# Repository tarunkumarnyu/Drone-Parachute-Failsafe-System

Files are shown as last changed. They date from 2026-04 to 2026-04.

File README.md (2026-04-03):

# Drone Failsafe Parachute System







An autonomous emergency recovery system for UAVs that detects in-flight failures and deploys a parachute with retractable landing gear for controlled descent — no pilot intervention required.

Built for the Mechatronics course (ROB-GY 5103) at NYU Tandon School of Engineering.

## Overview

Unmanned Aerial Vehicles are vulnerable to mid-flight failures — motor burnout, ESC faults, power loss — any of which can result in an uncontrolled crash. Conventional failsafes like return-to-home cannot recover from a dead motor or total power failure.

This system addresses that gap with a hardware-level emergency recovery pipeline built around the Parallax Propeller's multi-cog architecture. An MPU6050 IMU detects sudden acceleration anomalies (jerk-based freefall detection), triggering autonomous parachute deployment via servo-actuated topology-optimized release plates. Simultaneously, an HC-SR04 ultrasonic sensor monitors ground proximity and deploys spring-suspended retractable landing gear at a calibrated altitude threshold to absorb residual impact energy.

The entire pipeline — from failure detection to chute release to gear deployment — runs across dedicated parallel cogs with no shared blocking, achieving sub-100 ms end-to-end response latency.

<p align="center">
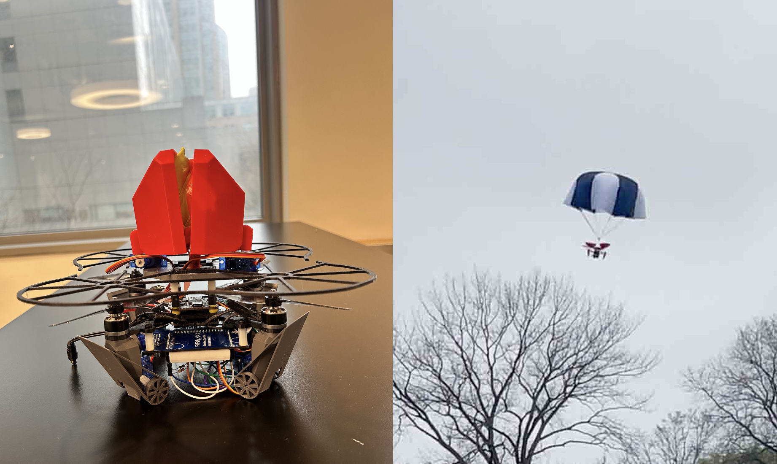
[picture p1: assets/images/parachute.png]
Drone Failsafe Parachute System
  
</p>

## Demo

https://github.com/user-attachments/assets/7736cbfe-6007-4965-8da9-a2f48488e733

https://github.com/user-attachments/assets/dcd64783-5e9d-4d79-8ad5-cde76a08081a
## How It Works

The firmware runs three concurrent processes on the Parallax Propeller's multi-core (cog) architecture, enabling true hardware-level parallelism with zero blocking between sensing and actuation:

**Stage 1 — Failure Detection (Cog 2: IMU Monitor)**

1. MPU6050 reads Z-axis acceleration at 20 Hz over I2C
2. Computes jerk (rate of change of acceleration) between consecutive readings
3. Sets an emergency flag when jerk exceeds the calibrated threshold — catches motor failure, ESC burnout, and freefall events

**Stage 2 — Parachute Deployment (Cog 0: Supervisor)**

1. Main supervisor loop detects jerk flag from IMU cog
2. Parachute servo rotates from armed (90°) to deployed (180°)
3. Topology-optimized plates open to allow clean chute separation from the airframe

**Stage 3 — Landing Gear Deployment (Cog 1: Ultrasonic Ranging)**

1. HC-SR04 continuously measures ground distance via pulse timing at ~10 Hz
2. When altitude drops below 35 cm, landing gear servo actuates
3. Spring-suspended 3D-printed gear absorbs remaining impact force

## System Architecture

<p align="center">
  Parallax Propeller Multi-Cog Architecture
</p>

## Components

| Component | Model | Qty | Purpose |
|---|---|-----|---|
| Microcontroller | Parallax Propeller P8X32A | 1 | Real-time multi-cog processing |
| IMU | MPU6050 | 1 | Z-axis jerk detection |
| Ultrasonic Sensor | HC-SR04 | 1 | Ground proximity ranging |
| Servo Motor | MG995 | 6 | Parachute release (2) + Landing gear (4) |
| Battery | 8.4V 2S LiPo | 1 | Main power supply |
| Buck Converter | — | 1 | 8.4V → 5V regulation |
| Drone Platform | Frame, FC, ESC, BLDC Motors | — | Flight platform |

## Pin Map

| Peripheral | Pin | Protocol |
|---|-----|---|
| MPU6050 SDA / SCL | P0, P1 | I2C |
| Parachute Servo | P2 | PWM |
| HC-SR04 Trig / Echo | P3 | GPIO |
| Landing Gear Servo | P4 | PWM |

## Design Decisions

- **Multi-cog concurrent sensing** — IMU and ultrasonic run on dedicated Propeller cogs for true parallel real-time processing with zero blocking
- **Jerk-based detection over tilt** — Computing the acceleration derivative catches sudden failures (motor loss, ESC burnout) faster than absolute tilt thresholds
- **Multi-stage descent sequencing** — Staged deployment (detect → chute → gear) inspired by proven planetary landing strategies
- **Topology-optimized release plates** — FEA-driven weight reduction while maintaining structural integrity and minimizing propeller wash drag
- **Spring-suspended landing gear** — Absorbs residual impact energy that the parachute alone cannot eliminate

## Results

- Autonomous parachute deployment on detected jerk events with <100 ms response latency
- Significant reduction in landing impact force across controlled test scenarios
- Reliable landing gear actuation at calibrated ground proximity threshold
- Validated against simulated motor failure, ESC burnout, and signal loss conditions

## Future Work

- Predictive stability control using onboard ML for preemptive deployment
- Adaptive deployment timing based on real-time environmental conditions (wind, altitude)
- Alternative energy absorption mechanisms (deployable air cushions, shock-absorbing retractable gear)
- Integration pathway for commercial drone platforms and regulatory compliance (FAA Part 107)

## Stack

`Parallax Propeller (C)` · `SimpleIDE` · `MPU6050` · `HC-SR04` · `MG995 Servos` · `SolidWorks` · `PLA-CF 3D Printing` · `LiPo Power System`

## Team

Tarunkumar Palanivelan · Sven Sunny · Abirami Palaniappan Sirsabesan

## License

This project is licensed under the [MIT License](LICENSE).

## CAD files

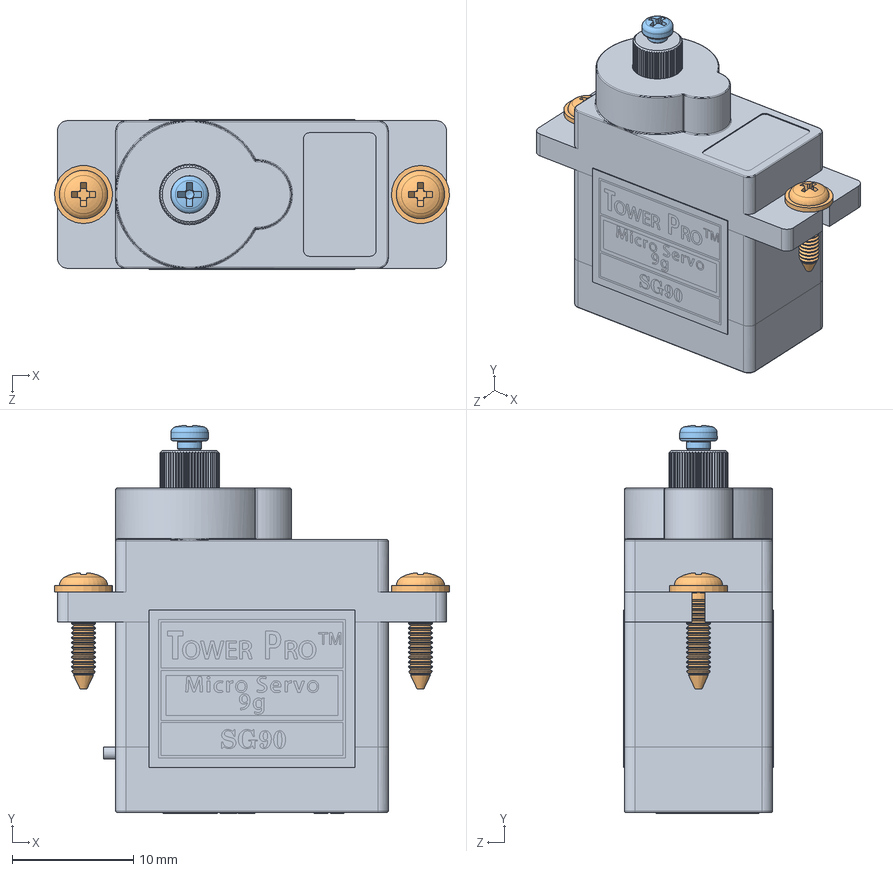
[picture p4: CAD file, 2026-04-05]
cadv2/SG90 - Micro Servo 9g - Tower Pro.SLDASM
32.6 x 32.0 x 12.4 mm
SG90 - Micro Servo 9g - Tower Pro.1
SG90 - Micro Servo 9g - Tower Pro.5 x 2
SG90 - Micro Servo 9g - Tower Pro.6

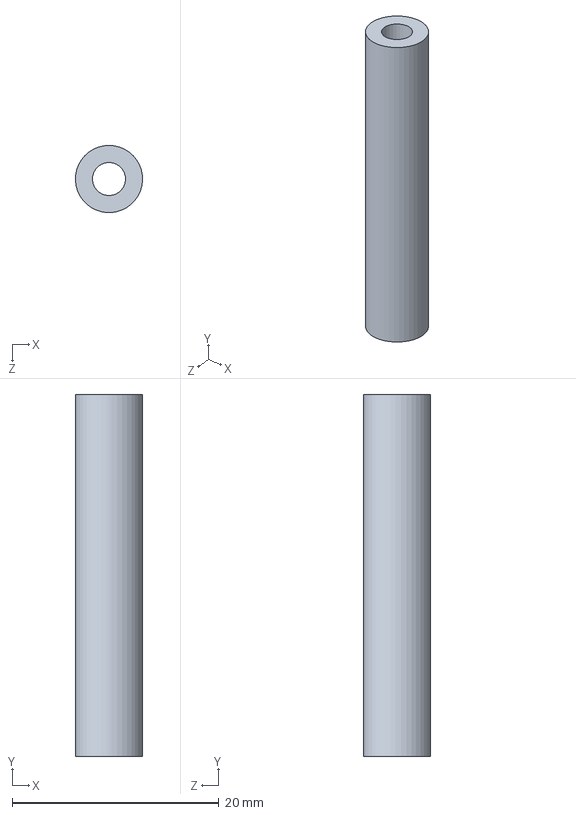
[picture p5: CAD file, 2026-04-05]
cadv1/spacers_35mm.SLDPRT
6.49 x 35.0 x 6.50 mm

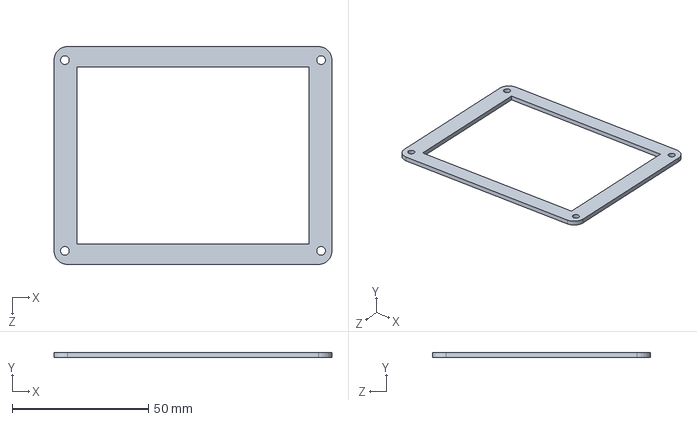
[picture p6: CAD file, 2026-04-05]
cadv2/servo holder.SLDPRT
102.0 x 2.00 x 80.0 mm

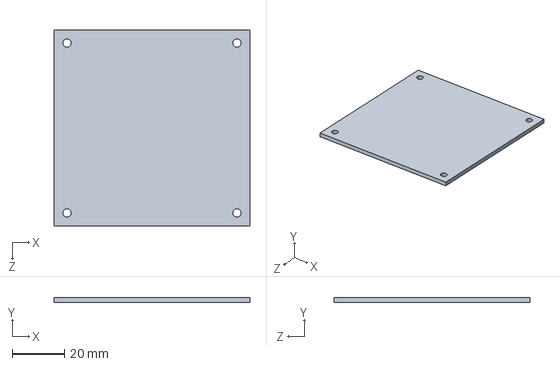
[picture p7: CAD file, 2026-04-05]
cadv1/arduino_attachment.SLDPRT
75.0 x 2.00 x 75.0 mm

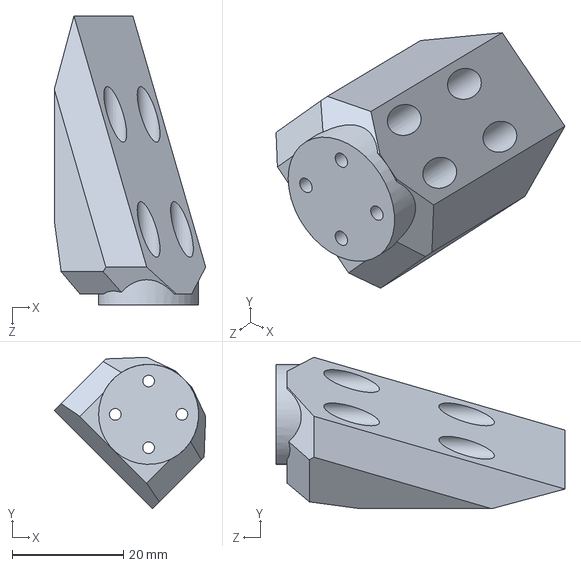
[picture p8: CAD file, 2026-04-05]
cadv2/lg.SLDPRT
27.2 x 27.2 x 52.0 mm

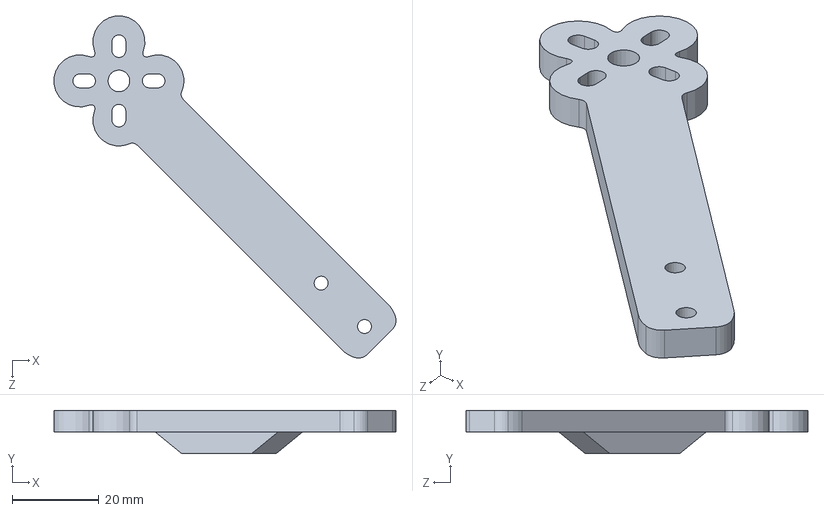
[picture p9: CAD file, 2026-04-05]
cadv1/frame_arms.SLDPRT
78.8 x 10.0 x 78.8 mm

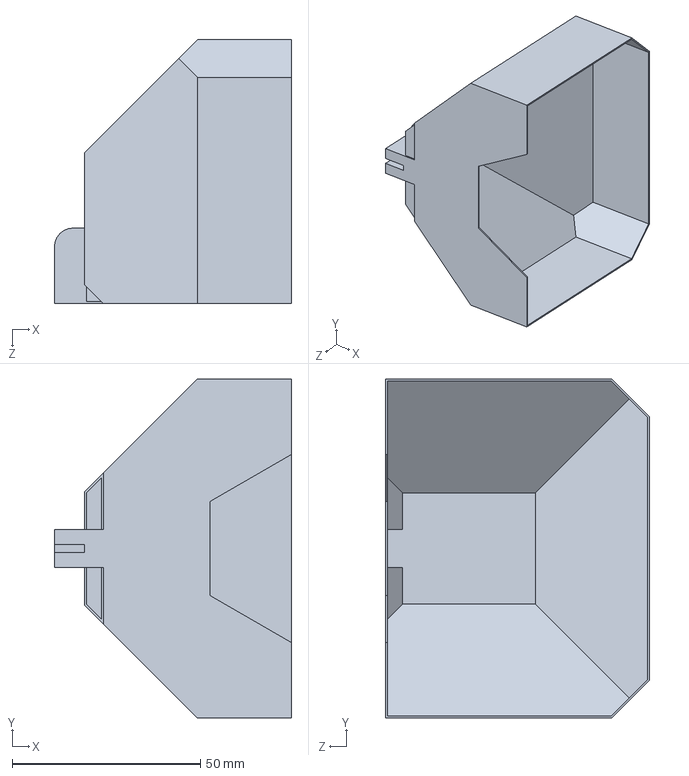
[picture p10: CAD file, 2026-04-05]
cadv2/parachute case.SLDPRT
63.0 x 90.0 x 70.0 mm

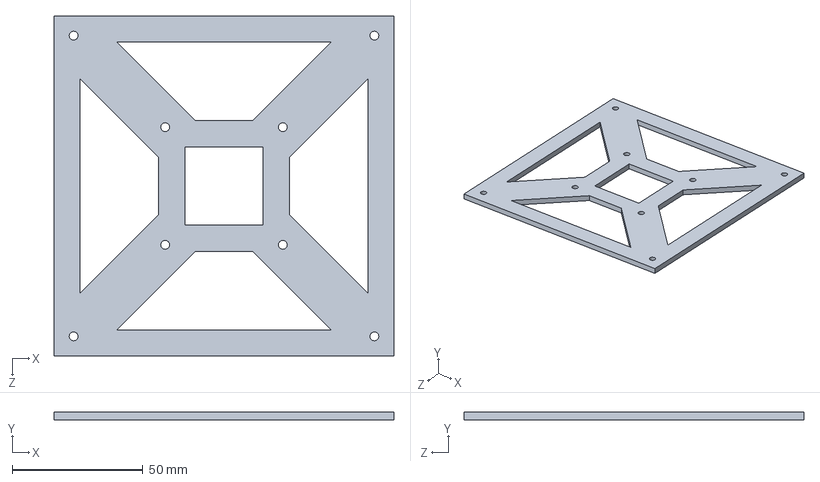
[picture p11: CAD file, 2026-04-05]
cadv1/case part1.SLDPRT
130.0 x 3.00 x 130.0 mm

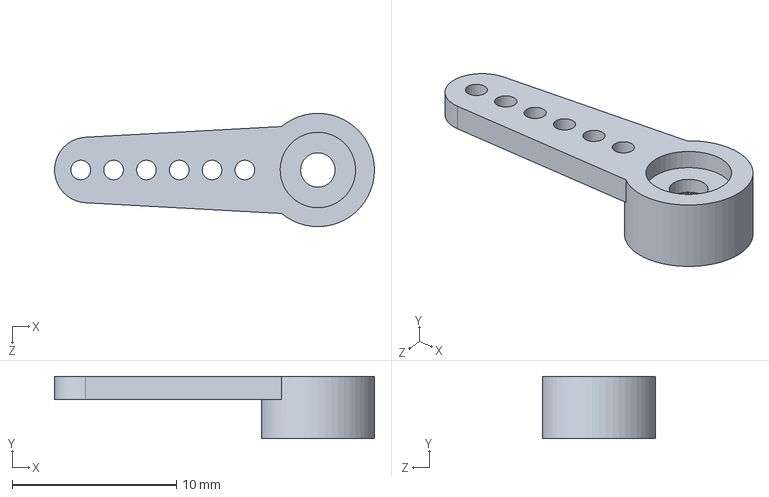
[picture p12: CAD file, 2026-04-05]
cadv2/SG90 - Micro Servo 9g - Tower Pro.2.SLDPRT
19.5 x 3.80 x 6.90 mm

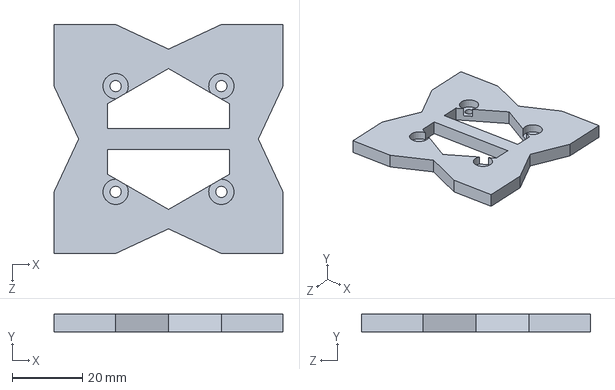
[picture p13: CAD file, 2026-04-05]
cadv2/parachute holder.SLDPRT
65.0 x 5.00 x 65.0 mm

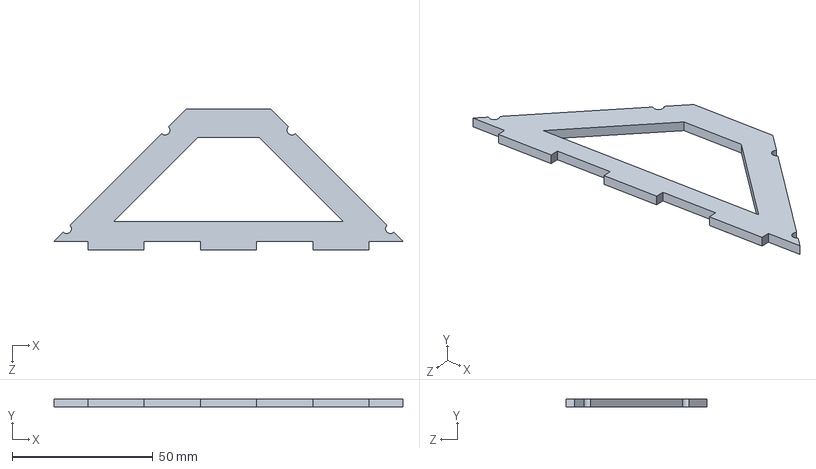
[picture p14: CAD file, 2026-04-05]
cadv1/top.SLDPRT
124.0 x 3.00 x 50.0 mm

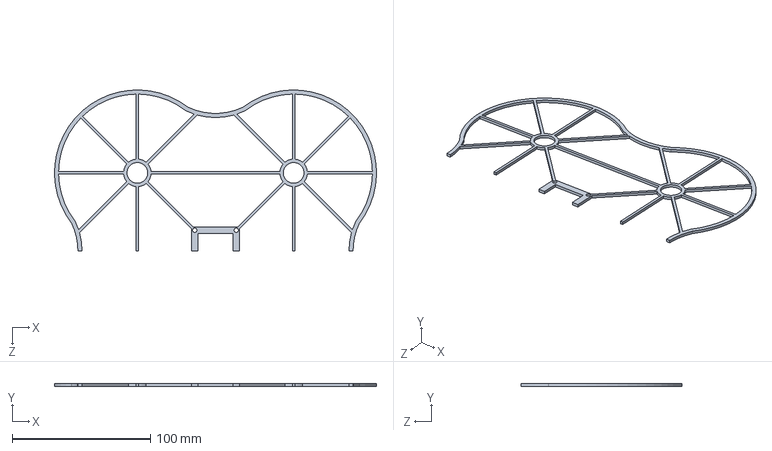
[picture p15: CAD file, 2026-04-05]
cadv2/prop guardhalf.SLDPRT
233.1 x 2.00 x 116.5 mm

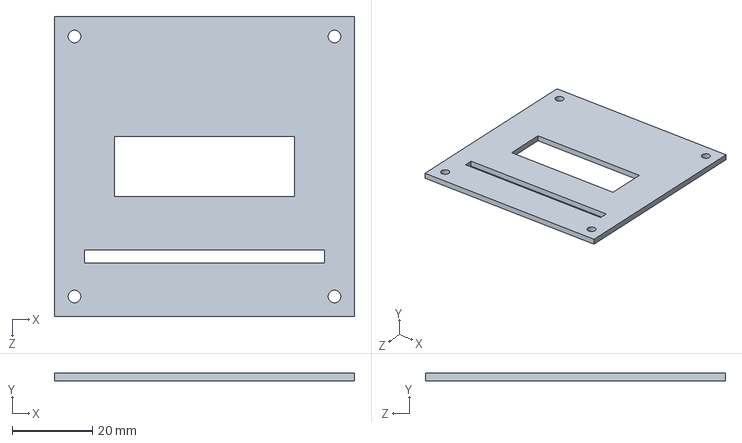
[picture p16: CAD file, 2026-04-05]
cadv1/sensors_attachment.SLDPRT
75.0 x 2.00 x 75.0 mm

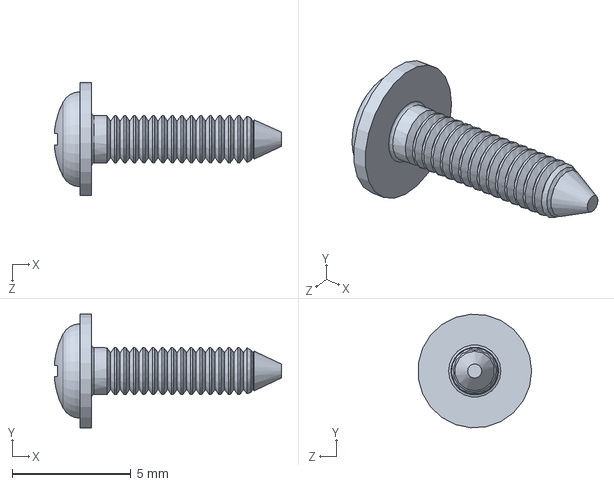
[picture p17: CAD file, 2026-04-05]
cadv2/SG90 - Micro Servo 9g - Tower Pro.5.SLDPRT
9.57 x 4.79 x 4.78 mm

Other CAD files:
cadv1/parachute_case_assem.SLDASM
cadv1/spacers_30mm.SLDPRT
cadv1/Parachute_holder.SLDPRT
cadv2/SG90 - Micro Servo 9g - Tower Pro.6.SLDPRT
cadv1/frame_base_1.SLDPRT
cadv1/side.SLDPRT
cadv1/spacer_15mm.SLDPRT
cadv2/SG90 - Micro Servo 9g - Tower Pro.1.SLDPRT
cadv2/SG90 - Micro Servo 9g - Tower Pro.4.SLDPRT
cadv2/lg e.SLDPRT

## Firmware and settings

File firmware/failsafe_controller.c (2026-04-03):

/**
 * failsafe_controller.c
 *
 * Multi-cog firmware for the Drone Failsafe Parachute System.
 * Runs on Parallax Propeller (P8X32A) using SimpleIDE toolchain.
 *
 * Architecture:
 *   Cog 0 (Main)  — Supervisor loop: reads shared flags, actuates servos
 *   Cog 1          — Ultrasonic ranging: continuous ground-proximity measurement
 *   Cog 2          — IMU monitor: Z-axis jerk detection for freefall/failure events
 *
 * Hardware:
 *   P0/P1  — I2C bus (MPU6050)
 *   P2     — Parachute release servo (PWM)
 *   P3     — HC-SR04 ultrasonic trigger/echo (GPIO)
 *   P4     — Landing gear deploy servo (PWM)
 */

#include "simpletools.h"
#include "servo.h"
#include "simplei2c.h"

/* ── Pin Assignments ─────────────────────────────────────────────────── */
#define PIN_I2C_SDA          0
#define PIN_I2C_SCL          1
#define PIN_SERVO_PARACHUTE  2
#define PIN_ULTRASONIC       3
#define PIN_SERVO_GEAR       4

/* ── MPU6050 Registers ───────────────────────────────────────────────── */
#define MPU6050_ADDR         0x68
#define REG_ACCEL_ZOUT_H     0x3F
#define REG_PWR_MGMT_1       0x6B

/* ── Thresholds ──────────────────────────────────────────────────────── */
#define JERK_THRESHOLD       9000   // Raw ADC delta triggering parachute deploy
#define GEAR_DEPLOY_CM       35     // Ground proximity threshold for landing gear

/* ── Servo Positions ─────────────────────────────────────────────────── */
#define PARACHUTE_ARMED      90
#define PARACHUTE_DEPLOYED   180
#define GEAR_STOWED          0
#define GEAR_DEPLOYED        1100

/* ── Shared State (volatile: accessed across cogs) ───────────────────── */
volatile int ground_distance_cm = 0;
volatile int jerk_detected      = 0;

/* ── Private State ───────────────────────────────────────────────────── */
static i2c *imu_bus;
static int  prev_accel_z  = 0;
static int  gear_deployed = 0;

/* ── Forward Declarations ────────────────────────────────────────────── */
void ultrasonic_ranging_task(void);
void imu_monitor_task(void);

/* ── MPU6050 Driver ──────────────────────────────────────────────────── */

static void mpu6050_write_reg(unsigned char reg, unsigned char value) {
    i2c_out(imu_bus, MPU6050_ADDR, reg, 1, &value, 1);
}

static int mpu6050_read_word(unsigned char reg) {
    unsigned char buf[2];
    i2c_in(imu_bus, MPU6050_ADDR, reg, 1, buf, 2);
    return (int)((buf[0] << 8) | buf[1]);
}

static void mpu6050_init(void) {
    mpu6050_write_reg(REG_PWR_MGMT_1, 0x00);
    pause(100);
}

/* ── Main Supervisor (Cog 0) ─────────────────────────────────────────── */

int main(void) {
    servo_angle(PIN_SERVO_GEAR, GEAR_STOWED);
    servo_angle(PIN_SERVO_PARACHUTE, PARACHUTE_ARMED);
    pause(1000);

    cog_run(ultrasonic_ranging_task, 128);

    imu_bus = i2c_newbus(PIN_I2C_SDA, PIN_I2C_SCL, 0);
    mpu6050_init();
    prev_accel_z = -mpu6050_read_word(REG_ACCEL_ZOUT_H);

    cog_run(imu_monitor_task, 128);

    while (1) {
        if (ground_distance_cm > 0 && ground_distance_cm <= GEAR_DEPLOY_CM && !gear_deployed) {
            servo_angle(PIN_SERVO_GEAR, GEAR_DEPLOYED);
            gear_deployed = 1;
        }

        if (jerk_detected) {
            servo_angle(PIN_SERVO_PARACHUTE, PARACHUTE_DEPLOYED);
            jerk_detected = 0;
        }

        pause(100);
    }

    return 0;
}

/* ── Ultrasonic Ranging Task (Cog 1) ─────────────────────────────────── */

void ultrasonic_ranging_task(void) {
    while (1) {
        low(PIN_ULTRASONIC);
        pause(2);
        high(PIN_ULTRASONIC);
        pause(10);
        low(PIN_ULTRASONIC);

        long echo_us = pulse_in(PIN_ULTRASONIC, 1);
        ground_distance_cm = echo_us / 58;

        pause(100);
    }
}

/* ── IMU Monitor Task (Cog 2) ────────────────────────────────────────── */

void imu_monitor_task(void) {
    while (1) {
        int accel_z = -mpu6050_read_word(REG_ACCEL_ZOUT_H);
        int jerk = accel_z - prev_accel_z;

        if (jerk > JERK_THRESHOLD) {
            jerk_detected = 1;
        }

        prev_accel_z = accel_z;
        pause(50);
    }
}

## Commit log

2026-04-02 Add firmware, docs, demo videos, and reorganize repo structure
    - firmware/ — Parallax Propeller C source and SimpleIDE config
    - docs/ — project report (original + commented) and presentation
    - assets/videos/ — demo, landing gear test, updated demo, raw footage
    - assets/images/ — system overview image
    - Updated README with actual code-based architecture details
2026-04-02 Replace ASCII architecture with Propeller architecture SVG
2026-04-02 Update README with user attachment links
    Added links to user attachment assets in the README.
2026-04-03 Professionalize firmware and README
    - Rename firmware to failsafe_controller.c with proper file header
    - Clean up code: named constants, structured sections, static scoping
    - Remove course references and project structure section from README
    - Fix team member name (Abirami Palaniappan Sirsabesan is one person)
    - Rewrite README with engineering-grade language and technical precision
    [failsafe_controller.c]
2026-04-05 Add CAD files — v1 and v2 SolidWorks assemblies and parts
    [Parachute_holder.SLDPRT, SG90 - Micro Servo 9g - Tower Pro.1.SLDPRT, SG90 - Micro Servo 9g - Tower Pro.2.SLDPRT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]

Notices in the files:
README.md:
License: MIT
